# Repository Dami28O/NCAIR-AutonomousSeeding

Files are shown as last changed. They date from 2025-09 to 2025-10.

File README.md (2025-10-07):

# NCAIR Autonomous Seeding Robot - "Àgbẹ̀"

## Overview

This repository contains the documentation and codebase for **Àgbẹ̀**, an autonomous seeding robot developed during a Robotics Internship with the National Center for Artificial Intelligence and Robotics (NCAIR) in Abuja, Nigeria.

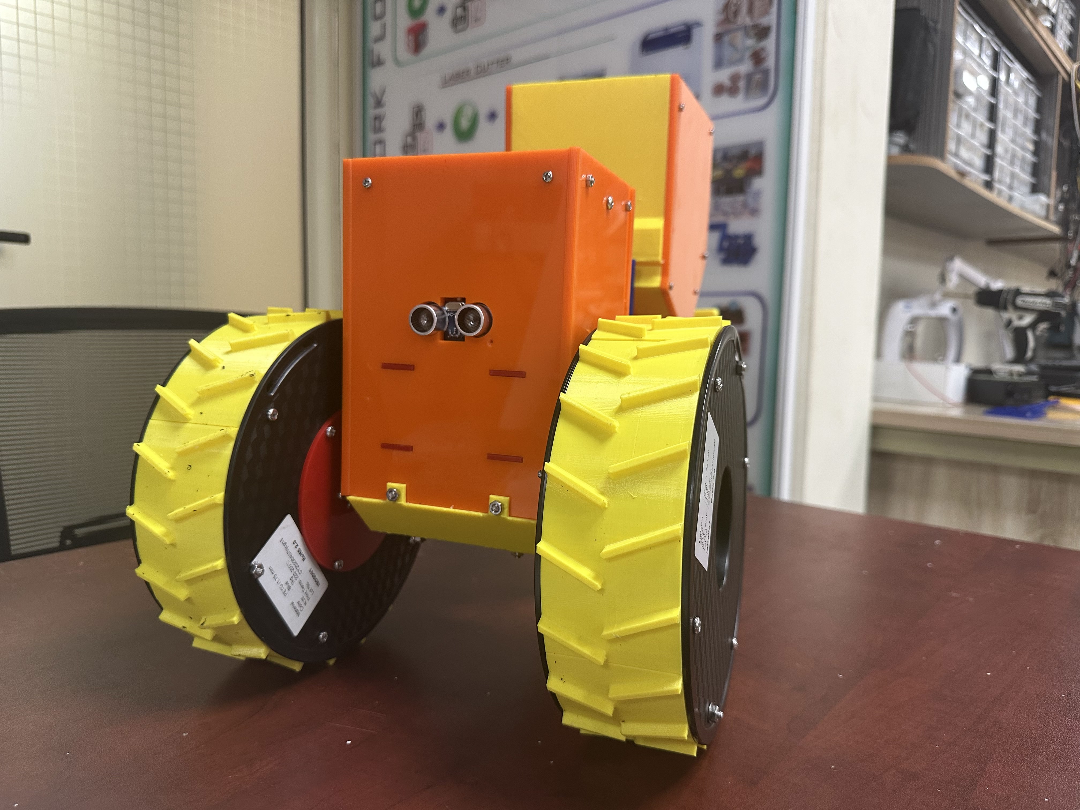
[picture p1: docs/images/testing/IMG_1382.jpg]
Àgbẹ̀


### Project Philosophy

- **Low Ground Pressure Design**: Minimizes soil compaction to preserve agricultural land quality
- **Swarm Approach**: Enables multiple units to work collaboratively for increased efficiency (Future Implementation)
- **Low Cost Solution**: Designed to be accessible and scalable for Nigerian agricultural contexts

---

# Repository Structure

```
NCAIR-AutonomousSeeding/
├── docs/
│   ├── hardware/
│   │   └── cad/                    # Fusion 360 CAD files
│   └── images/
│       ├── renders/                # 3D renders of the robot
│       ├── testing/                # Field testing images
│       ├── wiring/                 # Wiring diagrams
│       └── system_diagram/         # System architecture diagrams
├── architecture.md                 # Detailed description of the system architecture
├── evaluation.md                   # Evaluation of the current system
├── software/
│   ├── firmware/
│   │   ├── AutonomousSeeding.ino   # Motor control & sensor integration
│   │   └── wifi_comms.ino          # WiFi communication module
│   └── webapp/                     # Web application for robot control
│   │   ├── index.html  
│   │   ├── kalman.js
│   │   ├── main.js
│   │   └── styles.css 
├── architecture_evaluation.pdf     # Detailed architecture & product evaluation
├── assembly_guide.pdf              # Step-by-step assembly instructions
└── README.md                       # This file
```

---

## Architecture

For comprehensive details on the system architecture and product evaluation, please refer to [architecture.md](/docs/architecture.md) in the docs directory.

### System Overview

The Àgbẹ̀ robot employs a distributed control architecture with the following key components:

#### Hardware Architecture

**Mechanical Systems:**
- Low ground pressure chassis design (see `docs/hardware/cad/` for Fusion 360 files)
- Seeding mechanism with precise seed dispensing

**Electronics:**
- Microcontroller-based control system (Arduino-compatible)
- Sensor suite for navigation and environmental monitoring
- WiFi communication module for remote control
- Power management system

**Visual Resources:**
- **3D Models**: `docs/hardware/cad/` - Fusion 360 design files
- **Renders**: `docs/images/renders/` - High-quality visualizations
- **Wiring**: `docs/images/wiring/` - Complete wiring diagrams
- **System Diagrams**: `docs/images/system_diagram/` - Architecture overview

#### Software Architecture

**Firmware Layer:**

The robot operates on a dual-microcontroller architecture:

1. **Low-Level Control** (`software/firmware/AutonomousSeeding.ino`)
   - Motor control and PWM signal generation
   - Sensor data acquisition (GPS, IMU, proximity sensors)
   - Seeding mechanism actuation
   - Real-time control loops
   - Safety monitoring and emergency stop

2. **WiFi Communications** (`software/firmware/wifi_comms.ino`)
   - WiFi connectivity management
   - Remote command reception
   - Telemetry data transmission
   - Web interface integration

**Application Layer:**

3. **Web Application** (`software/webapp/`)
   - User interface for robot control
   - Real-time monitoring dashboard
   - Data visualization and logging
   - Framework: Vanilla JS

#### Communication Architecture

```
[Web Browser] <---> [Web App] <--WiFi--> [WiFi Comms Module] <--Serial--> [Low-Level Controller]

```
#### Technology Stack

**Embedded Systems:**
- Arduino-compatible microcontrollers
- C/C++ for firmware development
- Arduino Mega

**Web Technologies:**
- Frontend: Vanilla JS, Leaflet JS (GPS Visualisation) 
- WiFi communication protocol: HTTP

**Design Tools:**
- Autodesk Fusion 360 for mechanical design

---

## Documentation

### Core Documents

#### 📘 Architecture & Evaluation Documents
**File**: `architecture.md`

This comprehensive document covers:
- Detailed system architecture
- Hardware component specifications
- Software design rationale

**File**: `evaluation.md`
- Performance evaluation and testing results
- Design decisions and trade-offs

### Visual Documentation

#### `docs/images/renders/`
High-quality 3D renders showcasing:
- Complete robot assembly
- Individual subsystems

#### `docs/images/testing/`
Field testing documentation:
- Deployment photos
- Operational scenarios
- Performance demonstrations

#### `docs/images/wiring/`
Electrical documentation:
- Complete wiring diagrams
- Pin assignments
- Connection schematics
- Power distribution

#### `docs/images/system_diagram/`
System-level diagrams:
- Architecture overview
- Control system hierarchy
- Communication protocols

## Hardware Documentation

#### `docs/hardware/cad/`
Fusion 360 CAD files including:
- Complete assembly models
- Subsystem Model

---

## Getting Started

### Prerequisites

**Hardware Development:**
- Arduino IDE
- USB cable for microcontroller programming
- Components found in the [Bill Of Materials](/docs/BOM.md)

**CAD Viewing/Editing:**
- Autodesk Fusion 360 (for viewing/modifying CAD files)

**Web Development:**
- Webapp deployed locally from Python
- Web browser (Chrome/Firefox recommended)

### Assembly

1. **Mechanical Assembly**
   - Follow the complete instructions in `assembly_guide.pdf`
   - Use CAD files in `docs/hardware/cad/` for reference
   - Refer to `docs/images/renders/` for visual guidance

2. **Electronics Integration**
   - Follow wiring diagrams in `docs/images/wiring/`
   - Consult system diagrams in `docs/images/system_diagram/`
   - Double-check all connections before powering on

### Software Setup

#### Firmware Installation

**Low-Level Control Firmware**
```bash
    # Open AutonomousSeeding.ino in Arduino IDE
    # Select appropriate board and port
    # Open wifi_comms.ino in Arduino IDE
    # Configure WiFi credentials
    # Upload to primary microcontroller
```

#### Web Application Setup

```bash
cd software/webapp
python3 -m http.server 8080
```

---

## Usage

### Single Robot Operation

1. **Power On**: Flick Switch
2. **Connect**: Access web interface at [http://localhost:8080/] 
3. **Configure**: Set seeding parameters (spacing, depth, seed type)
4. **Deploy**: Define mission area and waypoints (Future implementation)
5. **Monitor**: Track progress via web dashboard

---

## Development

### Firmware Development

**Low-Level Control** (`software/firmware/AutonomousSeeding.ino`):
- Modify control algorithms
- Add new sensor support (Integration of rotary encoder)
- Adjust motor parameters
- Implement safety features

**WiFi Communications** (`software/firmware/wifi_comms.ino`):
- Update communication protocols
- Add new commands
- Improve telemetry
- Enhance swarm coordination

**Web Application** 
- Integration of kalman filter logic and tuning of kalman filter 
- Code structure optimisation

## Future Work

- [ ] Enhanced obstacle detection and avoidance
- [ ] Implement Boundary Detection and improved mapping
- [ ] Machine learning for optimal seeding patterns
- [ ] Extended battery life / solar integration
- [ ] Implement swarm algorithms for larger fleets
- [ ] Mobile app development
- [ ] Integration with precision agriculture sensors

---

## Acknowledgments

This project was completed as part of a Robotics Internship with the **National Center for Artificial Intelligence and Robotics (NCAIR)** in Abuja, Nigeria, under the National Information Technology Development Agency (NITDA).

### Project Name Origin

**Àgbẹ̀** - A Yoruba word meaning "farmer," reflecting the robot's purpose in supporting Nigerian agriculture.

## Quick Links

- 📘 [Architecture](/docs/architecture.md)
- 📘 [Evaluation](/docs/evaluation.md)
- 🔧 [Assembly Guide](/docs/assemblyGuide.md)
- 🎨 [3D Models (CAD)](./docs/hardware/cad/)
- 🖼️ [Renders](./docs/images/renders/)
- 📸 [Testing Photos](./docs/images/testing/)
- 🔌 [Wiring Diagrams](./docs/images/wiring/)
- 📊 [System Diagrams](./docs/images/system_diagram/)
- 💻 [Firmware](./software/firmware/)
- 🌐 [Web Application](./software/webapp/)

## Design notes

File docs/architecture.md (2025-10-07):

# System Architecture – Seeding Robot

## 1. Introduction
The seeding robot is designed to automate the process of planting seeds with consistent spacing and depth.  
This document explains the overall architecture, including the **mechanical design, electronics, software control**, and how these components interact.

---

## 2. System Overview
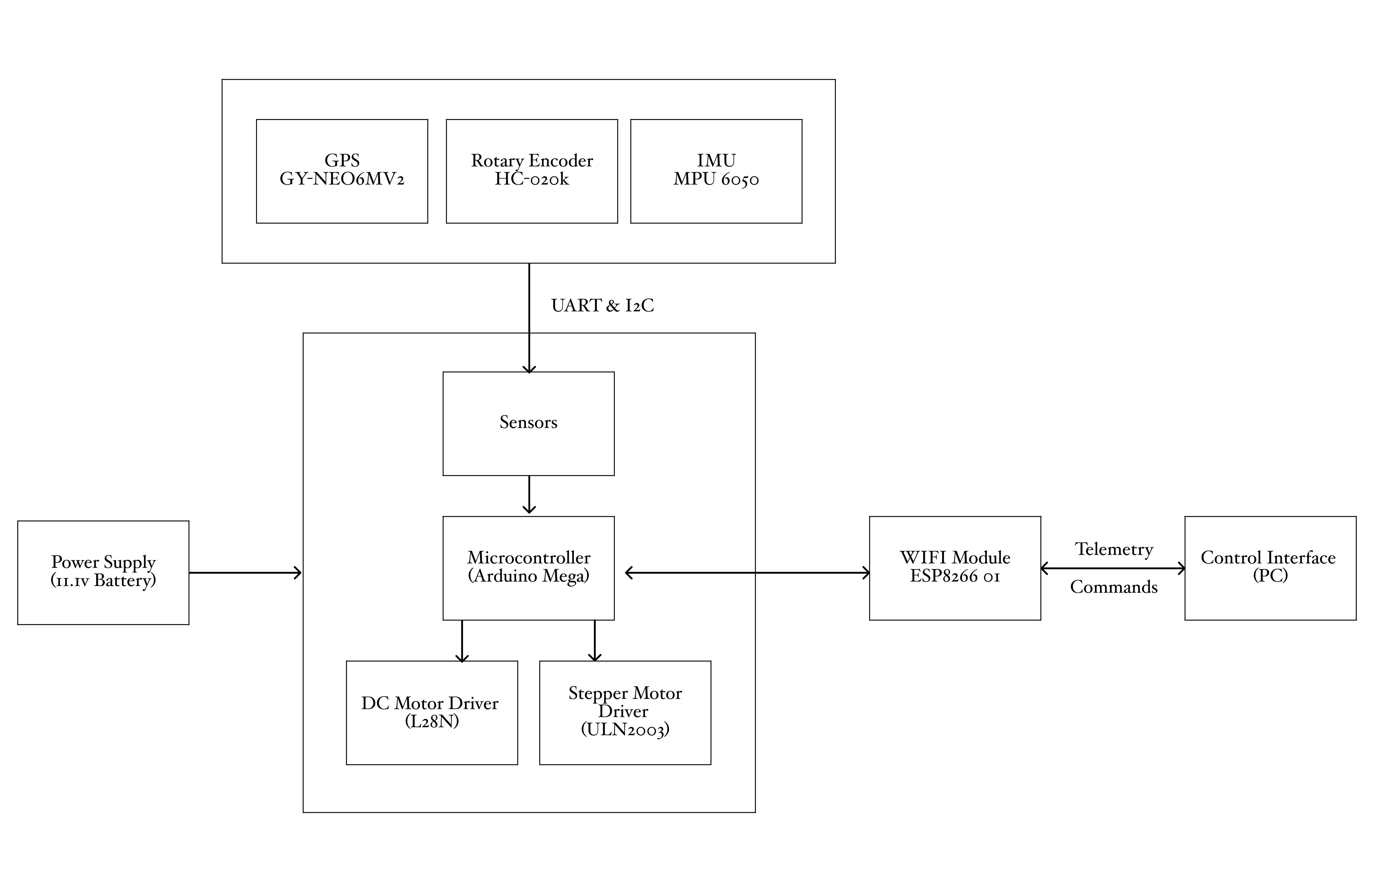
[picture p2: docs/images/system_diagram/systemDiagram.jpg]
System Block Diagram


The robot is divided into three main subsystems:
- **Mechanical** – chassis, wheel system, seed dispensing and furrow opening.
- **Electronics** – microcontroller, motor drivers, sensors, power supply, motors.
- **Software** – navigation and seed placement logic.

---

## 3. Mechanical Design
- **Chassis:** 
    - Dimensions: 632.74 x 278.00 × 390.47 mm (L × W × H).
    - Materials: Fabricated primarily from PLA (3D-printed components) and laser-cut acrylic sheets in 3 mm and 6 mm thicknesses, complemented by steel fasteners (M3, M4, M5 nuts, bolts, and washers) for structural integrity.
    - Wheels: The wheel assembly repurposes 198 mm-diameter recycled filament spools as the primary frame. Custom-designed PLA treads interlock with the spools and are mechanically fastened via screws to provide traction and durability.

- **Seeding Mechanism:**
    - **Seed Hopper & Feeding:** The hopper is designed with an angled base to direct seeds under gravity toward the dispensing mechanism. A 3D-printed converging funnel is installed at the outlet to constrain seed flow and minimize double-feeding. The geometry of the funnel is optimized to maintain a single-file feed, reducing seed bridging and clogging.

    - **Dispensing Mechanism:** At the base of the hopper, the dispensing unit is driven by a 28BYJ-48 Stepper Motor (precise 1.8° step angle). The motor is coupled to a laser-cut acrylic seed plate (interchangeable disc) with customizable pocket dimensions. Each pocket is sized according to seed diameter (e.g., 3–6 mm) and angular spacing, allowing adjustable seed drop frequency and spacing along the row. During rotation, each pocket aligns with an aperture slot at the bottom of the hopper, releasing a single seed through gravity drop.

    - **Furrow Opening & Closing:** The furrower is actuated via a rack-and-pinion mechanism coupled to a worm-and-spur gear train. A secondary stepper motor drives the worm, which in turn rotates the spur gear to raise or lower the rack. This motion adjusts the penetration depth of the furrow opener. The furrow opener itself consists of two 3 mm acrylic blades mounted on a pivot shaft with miniature ball bearings, allowing smooth rotation and reduced wear. The angled blades form a V-shaped cut, guiding soil outward to create a uniform seed trench.

- **Design considerations:**
    - **Soil resistance**: To overcome soil resistance during furrow actuation, a **worm gear** was selected to couple the stepper motor to the furrow mechanism due to its **non-backdrivability** and inherent torque multiplication. The chosen **28BYJ-48 stepper motors**, while offering low nominal torque, were favored for their **low power consumption** and compact form factor. To compensate for the torque limitations, a **1:60 gear reduction** was implemented between the worm gear and spur gear. This configuration substantially increased output torque, albeit at the expense of actuation speed. The reduced speed of raising and lowering the furrow was deemed acceptable given the critical requirement of ensuring sufficient penetration force in soil.

    - **Speed Spacing:** Seed spacing is governed by **wheel odometry**, derived from encoder counts at the rear wheel. For cost-efficiency, the system employs a **single rear-wheel encoder** rather than encoders on all wheels. With appropriate assumptions, this still yields an accurate estimate of distance traveled and thus seed placement intervals. Furthermore, the **planting interval is parameterizable via the web interface**, enabling calibration for different crop types and row spacing requirements.

    - **Wheel Configuration:** The robot employs a **tricycle-style wheel layout**, with a single drive wheel at the rear and two supporting wheels at the front. While unconventional, this arrangement was inspired by the **Fendt Xaver robot** design. A wider front wheelbase was chosen to enhance **lateral stability**, particularly in **tilled or soft soil conditions**, where narrower configurations risk instability or sinking.

    - **Electronics Housing:** 
        The electronics housing was designed to **integrate and protect** the power supply, microcontroller, and associated wiring within a single enclosure. This compartment is located at the **front of the robot**, serving a dual purpose:  
        1. **System Integration** – By consolidating the electronics into one housing, cable routing is minimized and maintenance is simplified, reducing potential points of failure in the field.  
        2. **Weight Distribution** – Positioning the housing at the front shifts the center of mass forward. When the seed hopper is fully loaded, this placement counterbalances the rear load and provides additional **downforce** on the furrow mechanism, improving soil penetration and stability during operation.

- CAD files are located in: [`/hardware/cad/`](../hardware/cad/).

---

## 4. Electronics
- **Microcontroller:** Arduino Mega
- **WIFI Module:** ESP8266 01
- **Motor Drivers:** 
    1. L28N Dual H-Bridge
    2. ULN2003 
- **Motors:**
    1. DC Motor with Gearhead 12VDC 74mA 1120 RPM ~ 1100 g-cm
    2. 28BYJ-48 stepper motors ~ 300g-cm
- **Sensors:** (GPS, IMU, encoders, soil sensors if any).  
    1. NEO6M-V2 GPS Module
    2. MPU6050 6DOF IMU
    3. HC-020K Rotary Encoder
    4. HC-SR04 Ultrasonic Sensor
- **Power Supply:** 11.1 Volt 3S Battery with 1200mAh

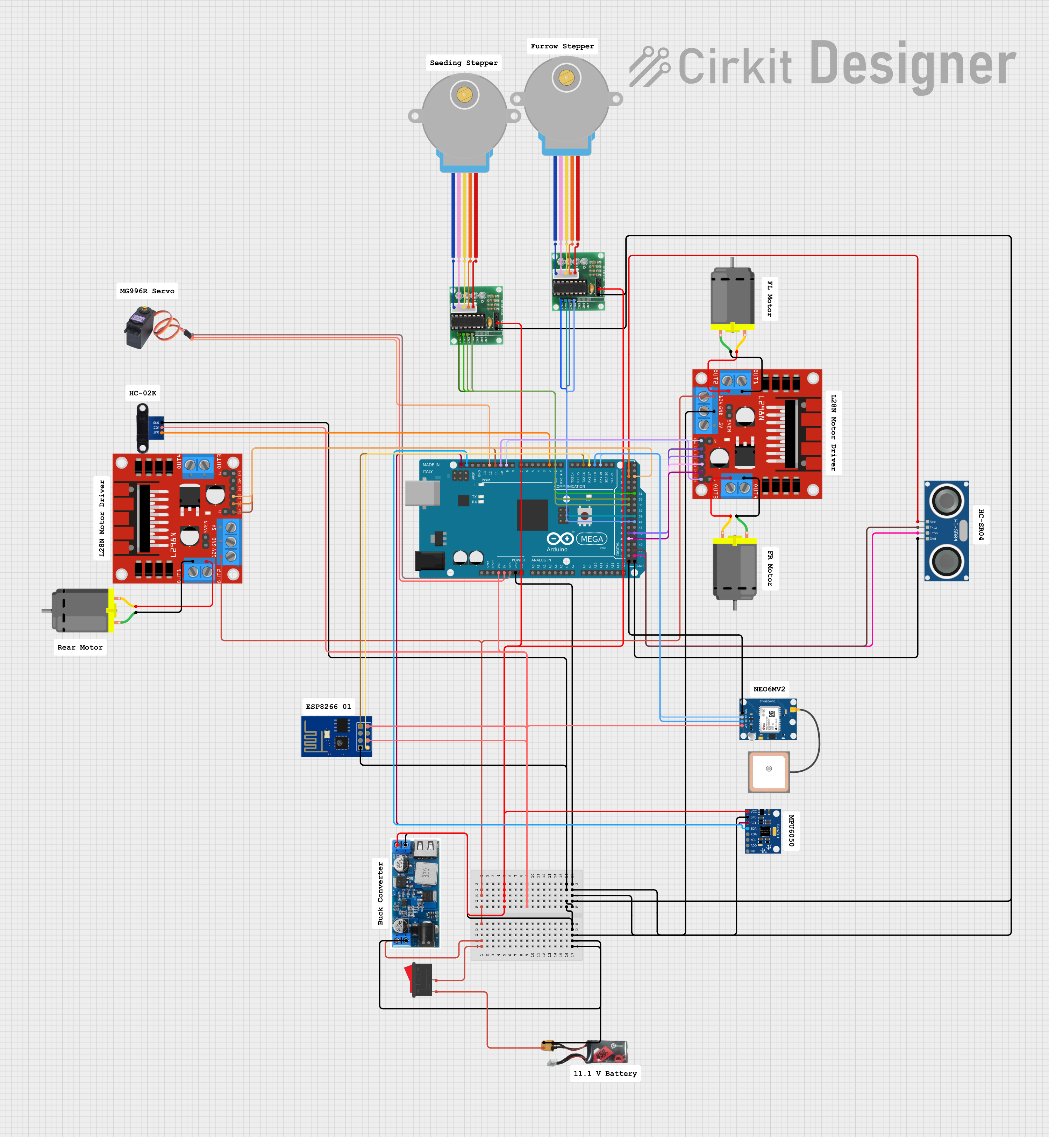
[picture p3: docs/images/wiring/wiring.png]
Wiring Diagram

Link: https://app.cirkitdesigner.com/project/0053ac62-e5af-4ed4-ab69-d646999af55c

---

## 5. Software Architecture
### 5.1 Control Layers
- **Low-Level (Firmware):** The low-level control is implemented on the Arduino Mega and is responsible for direct hardware interfacing and real-time task execution. This layer manages:
    - **Motor Control:**  
        - Implements PWM-based speed regulation for the DC drive motor via the L298N H-Bridge, supporting both forward and reverse motion.
        - Executes stepper motor sequencing for the 28BYJ-48 motors using the ULN2003 driver, enabling precise actuation of the seed dispensing plate and furrow depth mechanism.
        - Calculates differential wheel speeds based on Ackermann steering geometry, dynamically adjusting motor outputs for accurate path following.
    - **Sensor Polling & Data Acquisition:**  
        - Periodically reads encoder pulses from the HC-020K rotary encoder to compute wheel odometry and estimate linear displacement.
        - Polls the NEO6M-V2 GPS module and MPU6050 IMU over serial/I2C, parsing raw data for position and orientation updates.
        - Monitors the HC-SR04 ultrasonic sensor for obstacle detection, triggering avoidance routines if necessary.
    - **Seed Dispensing Logic:**  
        - Synchronizes seed drop timing with wheel odometry, activating the stepper-driven seed plate when the robot traverses the programmed interval distance.
        - Supports configurable seed spacing and drop frequency via parameters received from the web interface.
    - **Furrow Depth Actuation:**  
        - Controls the rack-and-pinion mechanism by driving the secondary stepper motor, adjusting furrow opener depth in response to user input or pre-set planting profiles.
    - **Communication:**  
        - Handles serial communication with the ESP8266 WiFi module, parsing incoming HTTP requests for control commands and transmitting sensor data to the web interface.
        - Implements a non-blocking main loop using timer interrupts and state machines to ensure responsive multitasking and minimize latency in sensor feedback and actuator control.
            - **Command Format:** HTTP GET requests to `http://<robot_ip>/<command>?speed=<val>&radius=<val>&depth=<val>`
            - **Supported Commands:** `forward`, `backward`, `left`, `right`, `stop`, `plant`, `pause_plant`, `furrow_up`, `furrow_down`
            - **Response Format:** JSON, e.g. `{"status":"OK"}`

- **High-Level:** navigation logic, sensor fusion (GPS + IMU + encoder).
    - **Navigation:**
        - In the current implementation, navigation and task execution are user-driven via the web-based control hub. The user interface allows manual specification of commands such as moving forward at a defined speed, planting seeds at a set depth, and executing turns with a configurable turning radius. These commands are transmitted to the robot as HTTP requests, which are parsed by the onboard ESP8266 module and relayed to the Arduino firmware for execution.
        - Each navigation command is mapped to low-level motor and actuator control routines, with parameters (speed, radius, depth) dynamically applied to the corresponding hardware interfaces. The robot does not autonomously plan its trajectory; instead, it responds to discrete user inputs in real time.
        - Future versions will incorporate autonomous navigation using path planning algorithms (e.g., A*, Dijkstra, or coverage planning) to optimise planting efficiency within a user-defined GPS boundary. The robot will continuously localize itself using fused GPS, IMU, and encoder data, and follow computed paths while automatically toggling planting actions based on its position and task schedule. This will enable fully autonomous operation, minimizing user intervention and maximizing throughput.
    - **Sensor Fusion:**  
        - Real-time localization of the robot is achieved through multi-sensor fusion using an extended Kalman filter (EKF), implemented off-board on the PC for computational efficiency and scalability. The decision to run the filter externally is driven by the high computational load and increased state dimensionality required for accurate pose estimation, which exceeds the capabilities of the onboard microcontroller.
        - The EKF prediction step integrates wheel odometry from the HC-020K rotary encoder and inertial measurements from the MPU6050 IMU (accelerometer and gyroscope). Since the IMU is limited to 6 degrees of freedom and lacks a magnetometer, absolute heading cannot be directly measured; instead, orientation is inferred by combining the servo steering angle and gyroscopic yaw rate, subject to kinematic constraints of the robot.
        - The correction step utilizes GPS position data from the NEO6M-V2 module, providing global 2D coordinates to correct drift in the predicted state. The filter fuses these asynchronous sensor streams, compensating for noise and bias, to output a continuous estimate of the robot’s position and orientation. This fused state is used for navigation, control, and logging, and can be extended to incorporate additional sensors or higher-order motion models as needed.

### 5.2 Autonomous Loop
```text
Start → Init (Read Sensors & Establish WiFi connection) → Get User Input → Start Operation 
→ [ Drive Forward → Lower Furrow → Plant Seeds → If Bounds < 2m → Pause Planting → Turn → Path Complete? ] 
→ If No → Repeat Loop 
→ If Yes → Stop

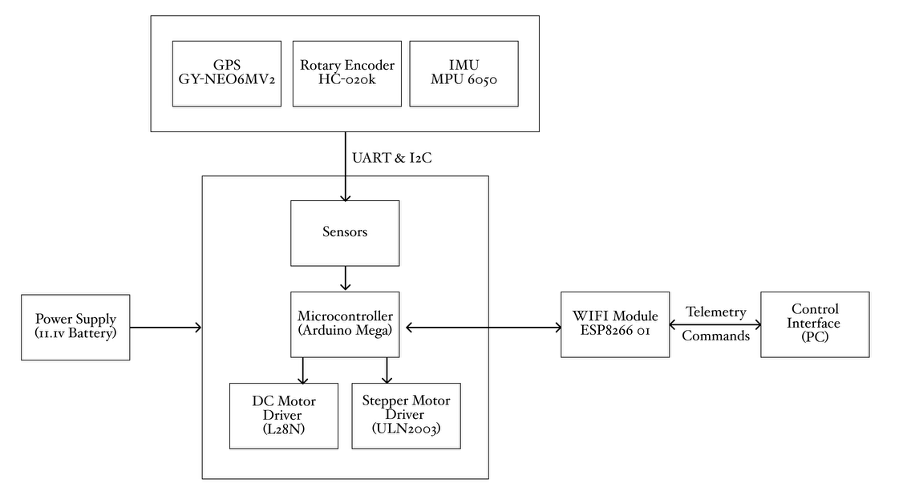
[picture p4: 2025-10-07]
docs/images/system_diagram/systemDiagram.png

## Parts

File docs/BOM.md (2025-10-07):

# Bill of Materials (BOM)

| Category | Component | Quantity | Purpose |
|---|---|---|---|
| **Motion** | Ultrasonic Sensor: HC-SR04 | 1 | Object detection to prevent collisions |
| | DC Motors | 3 | Motion |
| | Servo Motor (MG-996R) | 1 | 1× back wheel rotation |
| | Motor Driver: L298N | 2 | To drive the three wheels |
| | Rotary Encoder (Optical) - HC-020K | 1 | Backup for DC motor with encoder |
| | Neo 6m GPS | 1 | Robot localisation in space, used to create boundaries |
| | IMU - MPU6050 | 1 | To calculate orientation in space |
| **Seed Dispersion** | Stepper Motor: 28BYJ-48 (Box 068) | 2 | Turns the grate at set encoder readings to release grain at intervals |
| | Stepper Motor Driver: ULN2003 | 1 | Drives the stepper motor |
| | Ball Bearings | 2 | Furrow rotation |
| **MCU** | Arduino Mega | 1 | Main controller (“Brain”) |
| **Safety & Power** | Kill Switch | 1 | Stops the robot in case of malfunction |
| | Battery (11.1V) | 1 | Power supply |

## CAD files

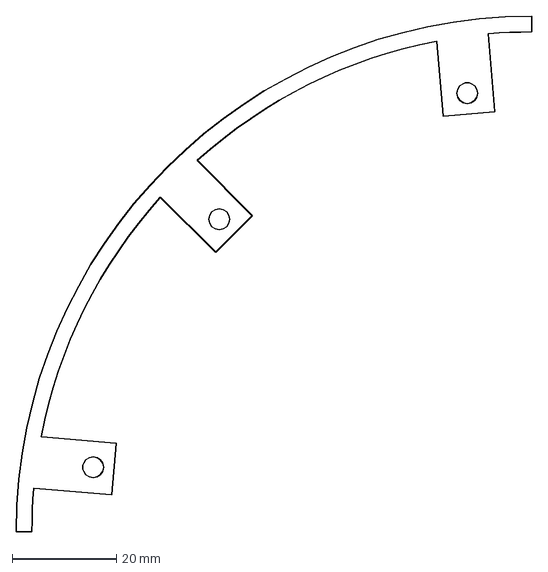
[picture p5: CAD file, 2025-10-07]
docs/hardware/cad/WheelGuide.dxf
99.0 x 99.0 mm

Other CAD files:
docs/hardware/cad/Seed Distribution System v19.f3z

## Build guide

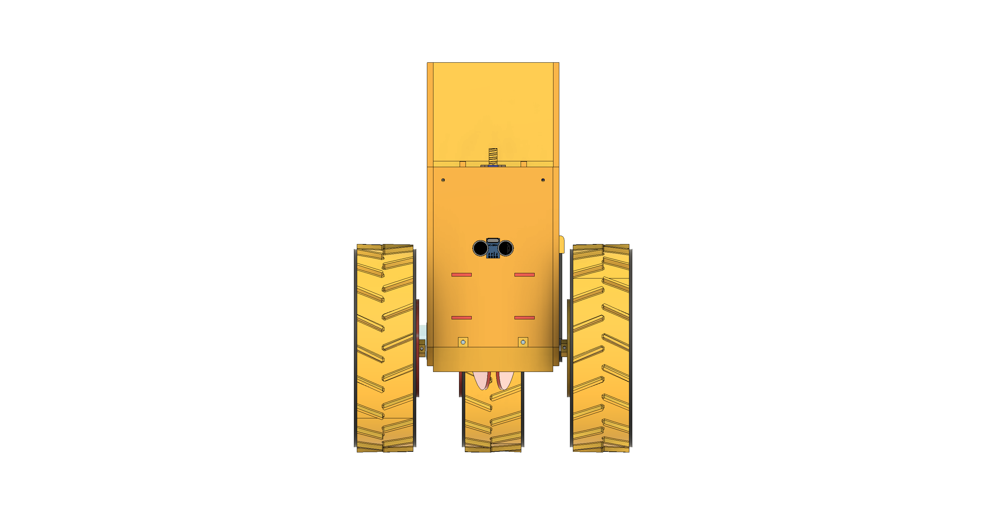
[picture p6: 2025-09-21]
docs/images/renders/Robot Assembly - FRONT.png

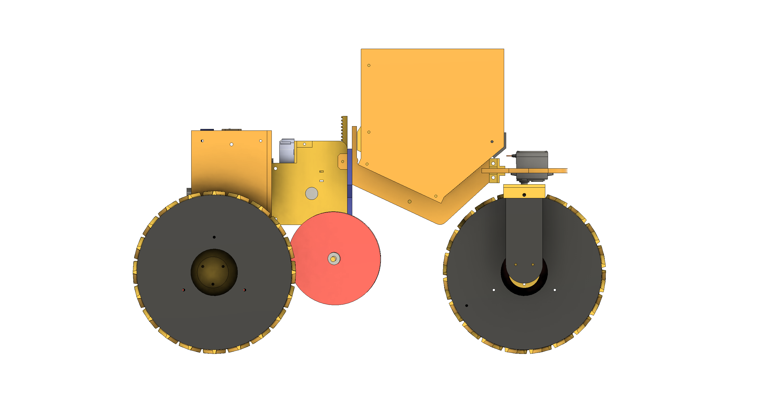
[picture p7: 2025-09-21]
docs/images/renders/Robot Assembly - LEFT.png

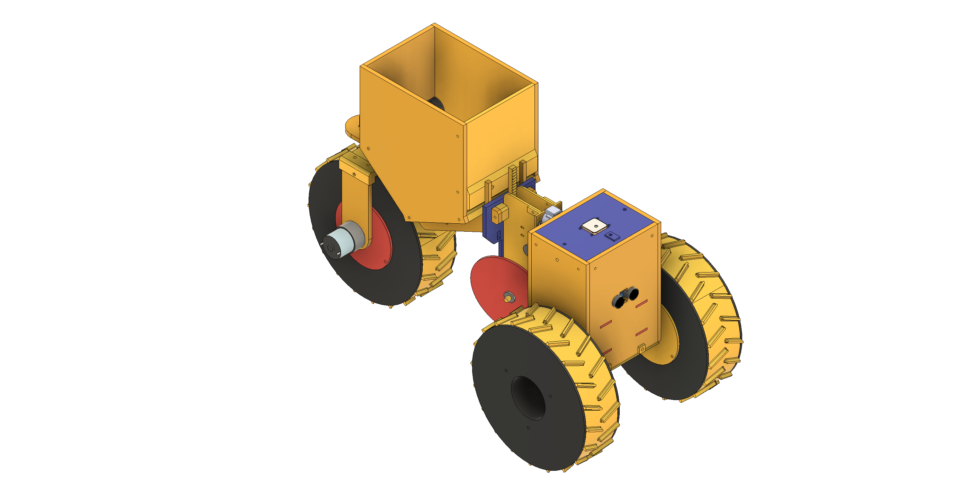
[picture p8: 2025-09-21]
docs/images/renders/Robot Assembly - ISO.png

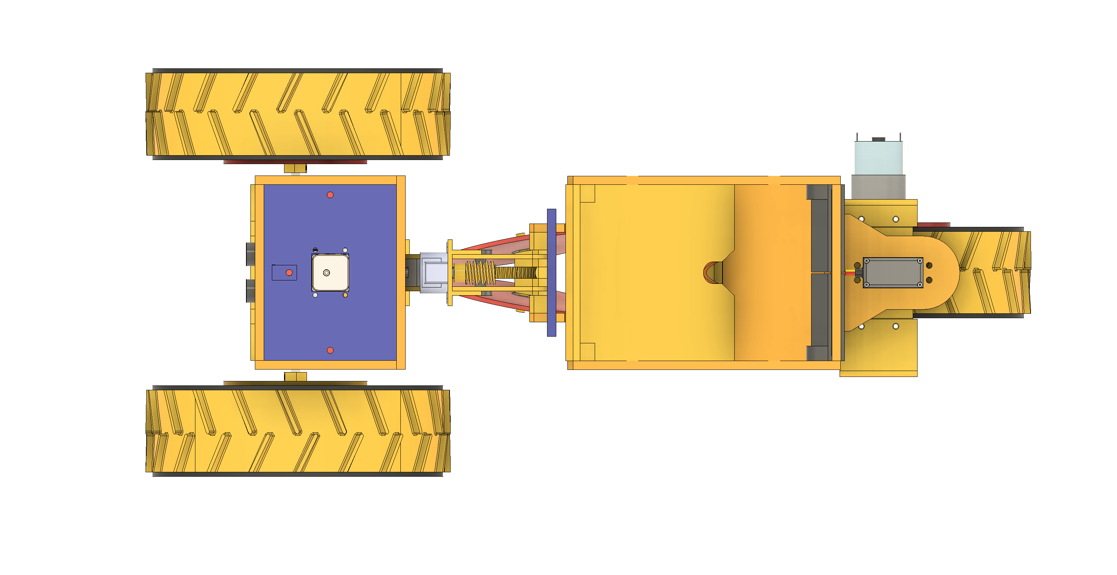
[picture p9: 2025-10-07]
docs/images/renders/Robot Assembly - TOP.png

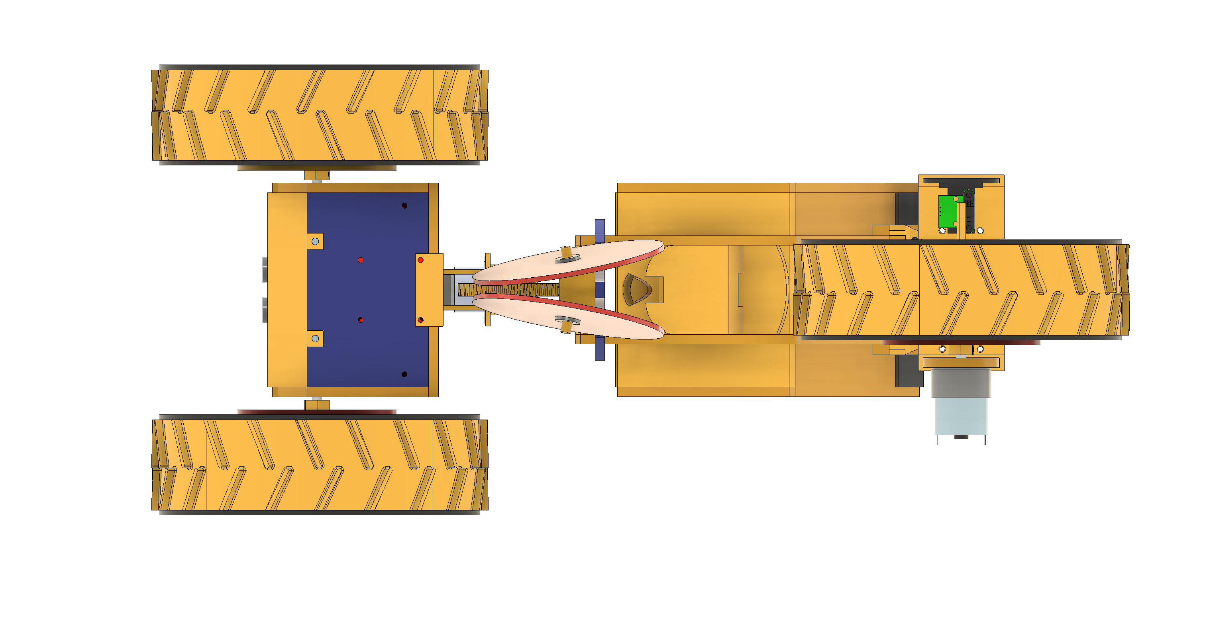
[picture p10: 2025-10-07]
docs/images/renders/Robot Assembly - BOTTOM.png

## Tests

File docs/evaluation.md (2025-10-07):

# Evaluation and Analysis of Current Implementation

## 1. Introduction

This document aims to critically analyse the current implementation and solution in addition to suggesting short-term and long-term improvements. Unfortunately a field test could not be completed, so it is likely further analysis needs to be conducted to understand how the robot performs in its operating environment. 

---

## 2. Mechanical Elements

### 2.1 Wheels

The current wheel design repurposes 3D printer filament spools as hubs, fitted with interlocking PLA treads. Due to the absence of a detailed assembly plan, inconsistencies arose during manufacturing—most notably, the rear wheel treads are slightly offset from center. This misalignment causes the raised tread sections to contact the servo mount, increasing friction, reducing drive efficiency, and occasionally stalling the motor. Such mechanical irregularities can introduce unpredictable behavior, complicating state estimation and localisation. To address this, future iterations should utilize the [Wheel Guide](/hardware/cad/WheelGuide.dxf) for precise assembly, and consider extending the guide to cover the full wheel circumference to prevent misalignment.

### 2.2 Structural Integrity 

The initial lack of a detailed assembly plan led to ad hoc design decisions regarding structural connections. While brass thermal inserts were considered for robust assembly, practical constraints necessitated alternative approaches, resulting in a structure with reduced rigidity. The modular design—comprising separate electronics housing, seed dispensing system, and rear wheel/servo modules—relies on a single laser-cut chassis piece for integration. Although this simplifies assembly, it introduces structural weak points and potential failure modes, particularly at the central chassis interface. For improved durability and reliability, future iterations should reinforce these connections and distribute mechanical loads across multiple attachment points to minimize dependence on a single structural element.

### 2.3 Design

Late-stage modifications to the electronics housing, such as adding an access port for Arduino debugging and firmware updates, were not fully integrated into the initial design. As a result, the port’s placement requires removal of the front right wheel for access, increasing maintenance complexity and accelerating wear on the wheel hub assembly. Similarly, the allocated space for battery recharging proved inadequate once the robot was fully assembled, complicating routine servicing. These oversights highlight the importance of design-for-maintenance principles; future iterations should prioritize accessible component placement and serviceability to streamline development, testing, and field repairs.

Assembly complexity was a significant challenge, particularly within the electronics hub. Once the battery and power distribution circuitry were installed, wiring became congested and disorganized, complicating both assembly and subsequent debugging. This increased build time and hindered fault isolation during testing. To address these issues, future iterations should implement systematic cable management and consider integrating a custom PCB to minimize external wiring and streamline assembly.

---

## 3. Software Elements 

### 3.1 Encoder

At this stage, the rotary encoder was not installed due to sourcing delays, limiting state estimation to low-frequency GPS updates. This constraint prevents accurate real-time odometry and degrades localisation performance, especially during maneuvers. Even with a rear-mounted encoder, wheel slippage can introduce measurement errors, and the absence of front wheel encoders impedes precise tracking during turns. While heading estimation can be partially compensated using gyroscope data, closed-loop speed and position control of the drive motors remains challenging without direct feedback. For the current semi-autonomous setup, users must manually estimate turn completion, which is inefficient and unreliable. Future designs should incorporate encoders on all driven wheels and consider mechanical improvements to minimise slippage, ensuring robust odometry for autonomous operation.

### 3.2 Sensor Fusion

While sensor fusion has been implemented on the PC side in javascript, further work needs be done to poll the sensors correctly from the robot. Currently, only GPS data is being transmitted so the remaining sensors have not been configured to send data properly, however timings can be inferred from the [mention file]

---

## 4. Further Implementation

### 4.1 Suspension

The current robot design lacks any form of suspension system, which significantly impacts its stability and operational reliability when traversing uneven or soft agricultural terrain. In the absence of suspension, shocks and vibrations from obstacles such as potholes, clods, or ruts are directly transmitted to the chassis and sensitive components, increasing the risk of mechanical wear, sensor inaccuracies, and loss of traction. This issue is exacerbated under load, where weight distribution can further amplify instability and wheel slip, potentially leading to erratic motion or stalling.

Integrating a suspension mechanism—such as spring-damper assemblies or flexible linkages—would decouple the chassis from ground-induced disturbances, maintaining consistent wheel contact and improving both traction and ride quality. This enhancement would not only protect onboard electronics and actuators from mechanical stress but also contribute to more accurate odometry and sensor readings, which are critical for reliable navigation and seed placement. Future iterations should prioritize the evaluation and implementation of suitable suspension architectures tailored for low-speed, lightweight field robots.

### 4.2 Navigation

As highlighted the current implementation is semi-autonomous but requires a lot of human input and monitoring for it be used. Implementing a navigation algorithm for path planning would enable this system to become fully autonomous. Below are some papers that tackle the issue of path planning for this exact use case.

**Relevant Links:**
- https://arxiv.org/abs/2210.07838
- https://www.mdpi.com/2073-4395/10/10/1608#:~:text=Agricultural%20field%20operations%20such%20as,ends%20at%20the%20same%20depot.

### 4.3 Modular Attachments

While this MVP is focused on seeding, the robot’s architecture is inherently modular, enabling rapid adaptation for a variety of agricultural tasks through interchangeable attachments. Adopting a tool-change paradigm similar to [OZ](https://www.naio-technologies.com/en/oz-robot/) by Naio Technologies, future iterations could support quick-swap modules for expanded functionality.

Potential modules include:
- **Camera Module:** Enables crop monitoring, weed and pest detection, and plant health assessment. Integrating an onboard computer vision pipeline would allow real-time analysis and decision-making in the field.
- **Weeding Module:** Mechanically removes weeds identified by the vision system, supporting precision agriculture and reducing manual labor. This could leverage existing mechanical or chemical weeding solutions, triggered by the detection module.

The modular approach not only increases the robot’s versatility but also streamlines maintenance and upgrades, as individual components can be serviced or replaced independently. Future work should focus on standardizing mechanical and electrical interfaces for attachments, and developing a robust software framework for dynamic tool recognition and control.

**Relevant Links:**
- https://link.springer.com/article/10.1007/s43154-022-00086-5

### 4.4 Swarm Approach

To further enhance operational efficiency, a swarm paradigm could be implemented, enabling multiple robots to collaboratively cover larger field areas. This approach allows the system to achieve throughput comparable to that of larger agricultural machinery, while minimising soil compaction and damage due to the distributed weight of smaller units. Swarm robotics also facilitates task specialisation, where individual robots can be equipped with different attachments (e.g., seeding, weeding, monitoring) and coordinate their actions to address diverse farm requirements. Implementing robust inter-robot communication and decentralized task allocation algorithms will be essential for effective collaboration and scalability in real-world agricultural environments.

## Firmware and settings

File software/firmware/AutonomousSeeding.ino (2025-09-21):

#include <Servo.h>
#include <AccelStepper.h>
#include <math.h>
#include <TinyGPSPlus.h>

// ---------------------------------------------------
//              PIN DEFINITIONS                       
// ---------------------------------------------------

// ------------ ULTRASONIC SENSOR
#define trigPin 52
#define echoPin 53

// ------------ DC MOTORS
// FR Motor connections
const uint8_t enFR = 9;
const uint8_t in1 = 44;
const uint8_t in2 = 45;

// FL Motor connections
const uint8_t enFL = 10;
const uint8_t in3 = 46;
const uint8_t in4 = 47;

// REAR Motor Connections
const uint8_t enREAR = 11;
const uint8_t REAR_in1 = 24;
const uint8_t REAR_in2 = 25;

// ------------ REAR SERVO
const uint8_t ServoSignal = 12;

// ------------ STEPPER MOTORS
#define HALFSTEP 8
AccelStepper seedingStepper(HALFSTEP, 30, 32, 31, 34); 
AccelStepper furrowStepper(HALFSTEP, 38, 40, 39, 41);


// ---------------------------------------------------
//              VARIABLE DEFINITIONS                       
// ---------------------------------------------------
const float WHEELBASE = 39.6;   // Distance between front and rear axles in cm
const float TRACK_WIDTH = 21.6; // Distance between front and rear axles in cm
int currentSpeed = 0;
bool isMovingForward = false;         
bool isDown = false;                            // Flag for furrow up or down
float furrowDepth = 0.0;                        // Gives us the depth of the furrow
const int MAX_DEPTH = 5;                        // Max depth of the furrow
const int STEPS_PER_REV = 2048;                 // for 28BYJ-48 in half-step mode
const int STEPS_30_DEG = STEPS_PER_REV / 12;    // ~170 steps for 30 degrees
const int DEFAULT_FURROW_ROT = 5;               // Default number of rotations to lower furrow to 3cm below ground 
bool planting = false;                          // Flag for planting mode or not 
unsigned long lastSeedDrop = 0;                 // Timer between seed drops
String lastMotionCommand = "";                  // Store the last valid motion command
bool stoppedByObstacle = false;                 // Flag to track if the stop was due to an obstacle
float lat = 9.0563;                             // last GPS lat and lon
float lng = 7.4985;
unsigned long lastGPSUpdate = 0;                // Timer for GPS updates
unsigned long servoMoveStartTime = 0;           // Timer to track servo movement  
bool servoMoving = false;                       // Flag to indicate if servo is moving 


// ---------------------------------------------------
//                   INSTANCES                      
// ---------------------------------------------------

Servo rearServo;                  // SERVO OBJECT
TinyGPSPlus gps;                  // GPS OBJECT


// ---------------------------------------------------
//              FUNCTION PROTOTYPES                      
// ---------------------------------------------------
void raiseFurrow(int numRot = DEFAULT_FURROW_ROT);
void lowerFurrow(int numRot = DEFAULT_FURROW_ROT);
void setupMotors();
void setupDCMotors();
void setupStepperServo();
void setupSensors();
void processCommand(String command);
int radiusToServoAngle(float radius, char dir);
void turn(char dir, int angle, float radius);
void rotateWheel(int angle);
void driveForward(float speed);
void driveBackward(float speed);
void stopMotors();
long readUltrasonic();
bool isServoReady();


// ---------------------------------------------------
//                   SETUP                      
// ---------------------------------------------------
void setup() {
  Serial.begin(9600);
  Serial1.begin(9600);                // GPS Serial

  // initialise the wifi connection
  initWiFi();

  // Setup robot functions
  setupMotors();
  setupStepperServo();
  setupSensors();

  // ------ SERVO ------ //
  rearServo.attach(ServoSignal);        // Servo signal wire → pin 12
  rearServo.write(90);        // Start centered
}

// -------------- SETUP FUNCTIONS -------------- //


void setupMotors() {
  setupDCMotors();
  setupStepperServo();
}

void setupDCMotors() {
  // Set all the motor control pins to outputs
  pinMode(enFR, OUTPUT);
  pinMode(enFL, OUTPUT);
  pinMode(enREAR, OUTPUT);
  pinMode(in1, OUTPUT);
  pinMode(in2, OUTPUT);
  pinMode(in3, OUTPUT);
  pinMode(in4, OUTPUT);
  pinMode(REAR_in1, OUTPUT);
  pinMode(REAR_in2, OUTPUT);

  // Turn off motors - Initial state
  digitalWrite(in1, LOW);
  digitalWrite(in2, LOW);
  digitalWrite(in3, LOW);
  digitalWrite(in4, LOW);
  digitalWrite(REAR_in1, LOW);
  digitalWrite(REAR_in2, LOW);
}

void setupStepperServo() {
  // Function to set up direction servo and two stepper motors

  // SERVO
  rearServo.attach(ServoSignal);        // Servo signal wire → pin 12
  rearServo.write(90);                  // Start centered

  // STEPPERS
  // Setup speed and acceleration for furrow and seeding stepper motors
  furrowStepper.setMaxSpeed(1000.0);
  furrowStepper.setAcceleration(50.0);

  seedingStepper.setMaxSpeed(1000.0);
  seedingStepper.setAcceleration(50.0);

  // Upon initialisation load the seeds to be ready for dropping
  loadSeeds();
}

void setupSensors() {
  // Set up ultrasonic sensor
  pinMode(trigPin, OUTPUT);
  pinMode(echoPin, INPUT);
}

// ---------- COMMAND PROCESSOR ----------- //
void processCommand(String command) {
  command.trim();                 // clean whitespace
  command.toUpperCase();          // Case insensitive

  if (command.startsWith("F")) {
    lastMotionCommand = command;                                // Save the direction and speed
    int speed = command.substring(1).toFloat();
    rotateWheel(90);
    driveForward(speed);
  } 
  else if (command.startsWith("B")) {
    lastMotionCommand = command;                                // Save the direction and speed
    int speed = command.substring(1).toFloat();
    rotateWheel(90);
    driveBackward(speed);
  }
  else if (command.startsWith("S")) {
    lastMotionCommand = "";                                     // Clear motion profile
    stopMotors();
  }
  else if (command.startsWith("L") || command.startsWith("R")) {
    lastMotionCommand = command;                                    // Save information on turning in case of obstacle
    char direction = command[0];                                    // Get direction from command
    float turningRadius = command.substring(1).toFloat();           // [cm]
    int angle = radiusToServoAngle(turningRadius, direction);       // Convert turning radius to angle 
    stopMotors();                                                   // Pause Motion
    
    turn(direction, angle, turningRadius);                           // Apply Ackermann Steering
  }
  else if (command.startsWith("U")) {
    // If the furrow is already down then bring back up
    if (isDown) {
      raiseFurrow();
    }
    else {
      Serial.println("Furrow is already up");
    }
  }
  else if (command.startsWith("D")) {
    if (isDown) {
      Serial.println("Furrow is already down");
    }
    else {
      lowerFurrow();
    }
  }
  else if (command == "PLANT") {
    // GO for planting seeds
    planting = true;
    Serial.println("Seeding mode activated");
  }
  else if (command == "PAUSE") {
    // GO for planting seeds
    planting = false;
    Serial.println("Seeding mode deactivated");
  }
  else {
    Serial.println("Invalid command.");
  }
}

// -------------- LOCOMOTION -------------- //
int radiusToServoAngle(float radius, char dir) {
  // Handle special cases
  if (radius <= 0) {
    Serial.println("Error: Radius must be positive");
    return 90;                                            // Return center position for invalid input
  }
  
  if (radius > 1000) {                                    // Very large radius = straight line
    return 90;
  }

  Serial.print("Direction "); Serial.println(dir);

  // Calculate steering angle with Ackermann steering
  float steeringAngleRad = atan(WHEELBASE / radius);
  float steeringAngleDeg = steeringAngleRad * 180.0 / PI; // Convert to degrees

  // Convert to servo position
  int servoAngle = (dir == 'R') ? (90 - (int)steeringAngleDeg) : (90 + (int)steeringAngleDeg);

  
  // Constrain to servo limits
  servoAngle = constrain(servoAngle, 0, 180);

  // Debug output
  Serial.print("Radius: "); Serial.print(radius);
  Serial.print(" cm -> Steering angle: "); Serial.print(steeringAngleDeg);
  Serial.print("° -> Servo angle: "); Serial.println(servoAngle);
  
  return servoAngle;
}


void turn(char dir, int angle, float radius) {
  int vR = 100;                          // Speed of rear wheel (PWM)
  int vFR = 0;                           // Initialise speed of front right wheel
  int vFL = 0;                           // Initialise speed of front right wheel
  // Turn the back wheel 
  rotateWheel(angle);
  
  while (!isServoReady()) {
    delay(10);  // Small delay to prevent busy waiting
  }


  // Compute Ackerman steering velocities
  if (dir == 'R') {
    vFR = round(vR * ((radius - TRACK_WIDTH / 2) / radius));
    vFL = round(vR * ((radius + TRACK_WIDTH / 2) / radius));
  }
  else {
    vFR = round(vR * ((radius + TRACK_WIDTH / 2) / radius));
    vFL = round(vR * ((radius - TRACK_WIDTH / 2) / radius));
  }

  // Constrain to valid PWM values
  vFR = constrain(vFR, 0, 255);
  vFL = constrain(vFL, 0, 255);

  // Apply calculated speed to drive motors
  // Set speed
  analogWrite(enFR, vFR);
  analogWrite(enFL, vFL);
  analogWrite(enREAR, vR);

  // Drive all three motors
  digitalWrite(in1, HIGH); digitalWrite(in2, LOW);
  digitalWrite(in3, LOW); digitalWrite(in4, HIGH); 
  digitalWrite(REAR_in1, LOW); digitalWrite(REAR_in2, HIGH);
  
  // Update state variables
  isMovingForward = true;
  currentSpeed = vR;

  Serial.print("Turning at "); Serial.println(vR);


  Serial.print("Rear servo angle: "); Serial.print(angle); Serial.print(" | ");
  Serial.print("Right Wheel Speed: "); Serial.print(vFR); Serial.print(" | ");
  Serial.print("Left Wheel Speed: "); Serial.println(vFL);
}

void rotateWheel (int angle) {
  rearServo.write(angle);
  servoMoveStartTime = millis();
  servoMoving = true;
  Serial.print("Moved to: ");
  Serial.println(angle);
}

bool isServoReady() {
  if (!servoMoving) return true;
  
  if (millis() - servoMoveStartTime > 600) {  // Adjust timing
    servoMoving = false;
    return true;
  }
  return false;
}

void driveForward(float speed) {
  // convert speed percent to PWM signal
  int PWM = int((speed/100) * 255);

  // Set speed
  analogWrite(enFR, PWM);
  analogWrite(enFL, PWM);
  analogWrite(enREAR, PWM);

  // Drive all three motors
  digitalWrite(in1, HIGH); digitalWrite(in2, LOW);
  digitalWrite(in3, LOW); digitalWrite(in4, HIGH); 
  digitalWrite(REAR_in1, LOW); digitalWrite(REAR_in2, HIGH);
  
  // Update state variables
  isMovingForward = true;
  currentSpeed = PWM;

  Serial.print("Driving forward at: "); Serial.println(PWM);
}

void driveBackward(float speed) {
  // convert speed percent to PWM signal
  int PWM = int((speed/100) * 255);

  // Set speed
  analogWrite(enFR, PWM);
  analogWrite(enFL, PWM);
  analogWrite(enREAR, PWM);

  // Drive all three motors
  digitalWrite(in1, LOW); digitalWrite(in2, HIGH);
  digitalWrite(in3, HIGH); digitalWrite(in4, LOW);
  digitalWrite(REAR_in1, HIGH); digitalWrite(REAR_in2, LOW);

  // Update state variables
  isMovingForward = false;
  currentSpeed = PWM;

  Serial.print("Driving backward at: "); Serial.println(PWM);
}

void stopMotors(){

  // Set PWM to 0
  analogWrite(enFR, 0);
  analogWrite(enFL, 0);
  analogWrite(enREAR, 0);

  // Update State Variables
  isMovingForward = false;
  currentSpeed = 0;
  

  Serial.print("Stopping DC Motor"); Serial.print(" | "); Serial.println("Planting Paused");
}

void resumeMotion() {
  // Check if there's a stored command to resume
  if (lastMotionCommand.length() > 0) {
    if (lastMotionCommand.startsWith("F")) {
      int speed = lastMotionCommand.substring(1).toFloat();
      driveForward(speed);
    } else if (lastMotionCommand.startsWith("B")) {
      int speed = lastMotionCommand.substring(1).toFloat();
      driveBackward(speed);
    } else if (lastMotionCommand.startsWith("L") || lastMotionCommand.startsWith("R")) {
      char direction = lastMotionCommand[0];                                    // Get direction from command
      float turningRadius = lastMotionCommand.substring(1).toFloat();           // [cm]
      int angle = radiusToServoAngle(turningRadius, direction);       // Convert turning radius to angle 
      stopMotors();                                                   // Pause Motion
      
      turn(direction, angle, turningRadius);                           // Apply Ackermann Steering
    }
  }
}

// ----------- FURROW ------------ //
void raiseFurrow(int numRot = DEFAULT_FURROW_ROT) {
  furrowStepper.moveTo(STEPS_PER_REV * numRot);              // Stepper moves anticlockwise
  furrowStepper.run();
  isDown = false;
  Serial.println("Furrow position reset");
}

void lowerFurrow(int numRot = DEFAULT_FURROW_ROT) {
  furrowStepper.moveTo(STEPS_PER_REV * -numRot);              // Stepper moves clockwise
  furrowStepper.run();
  isDown = true; 
  Serial.println("Furrow is now lowered");
}

// ----------- SEEDING ------------ //

void loadSeeds() {
  // Function to spin the stepper motor for the seeds so that it is ready to drop seeds periodically
  seedingStepper.moveTo(STEPS_30_DEG * 5);
  seedingStepper.run();
  lastSeedDrop = millis();
  Serial.println("Seeds ready to drop");
}

void dropSeeds() {
  // Rotate 30 degrees to drop one seed at a time
  seedingStepper.moveTo(seedingStepper.currentPosition() + STEPS_30_DEG);
  Serial.println("Seed dropped");
}

// ----------- SENSORS ------------ //

long readUltrasonic() {
  digitalWrite(trigPin, LOW);
  delayMicroseconds(2);
  digitalWrite(trigPin, HIGH);
  delayMicroseconds(10);
  digitalWrite(trigPin, LOW);
  long duration = pulseIn(echoPin, HIGH);
  return duration * 0.034 / 2; // cm
}

// GPS 
void simulateGPSMovement() {
  if (millis() - lastGPSUpdate > 5000) { // Update every 5 seconds
    // Simulate small random movements
    lat += (random(-10, 11) / 100000.0);
    lng += (random(-10, 11) / 100000.0);
    lastGPSUpdate = millis();
    
    Serial.print("GPS Update: ");
    Serial.print(lat, 6);
    Serial.print(", ");
    Serial.println(lng, 6);
  }
}



void loop() {
  // CHECK OBSTACLES AHEAD
  float distance = readUltrasonic();
  // Serial.print("Distance: ");
  // Serial.println(distance);

  // if valid gps data, pass that to the web-app else simulate ut
  if (Serial1.available()) {
    if (gps.encode(Serial1.read()) && gps.location.isValid()) { // if we can read the serial data and it is valid
      if (millis() - lastGPSUpdate > 5000) {
        lat = gps.location.lat();
        lng = gps.location.lng();
        lastGPSUpdate = millis();
      }
    }
  }
  else {
    simulateGPSMovement();
  }
  

  if (distance < 20 && isMovingForward) {
    stoppedByObstacle = true;
    stopMotors();
    Serial.println("Obstacle detected! Motors stopped.");
  }
  else if (stoppedByObstacle && distance >= 20) {
    // Resume prior action 
    resumeMotion();
    stoppedByObstacle = false;                    // Reset the flag after resuming
  }

  if (planting && isMovingForward) {
    // if in planting mode and the time since last drop is more than 2s -> drop a seed
    if (millis() - lastSeedDrop >= 2000) {
      dropSeeds();
      lastSeedDrop = millis();
    }
  }

  handleWiFiCommands();
  
  // Check for serial input
  if (Serial.available()) {
    String input = Serial.readStringUntil('\n');
    processCommand(input);
  }

  delay(10);
}

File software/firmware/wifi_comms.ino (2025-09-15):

// Handles all wifi communications for robot control
#include <WiFiEspAT.h>


// WiFi credentials for Access Point
char ssid[] = "AGBE";     
char pass[] = "AGBE@Seeding"; 

WiFiServer server(80); // Standard HTTP port

// ---------- FUNCTION DECLARATIONS
void sendWiFiResponse(WiFiClient client, String message, String contentType = "text/html");
String processWiFiCommand(String request);
int extractSpeedParameter(String request, int defaultSpeed);
float extractRadiusParameter(String request, float defaultRadius);
float extractDepthParameter(String request, float defaultDepth);

// Initialize WiFi
void initWiFi() {
  Serial2.begin(115200);   // ESP8266 connection

  Serial.println("=== Arduino Robot Control ===");
  Serial.println("Starting WiFi setup...");

  WiFi.init(&Serial2);

  // Check ESP8266 connection
  if (WiFi.status() == WL_NO_MODULE) {
    Serial.println("ERROR: ESP8266 not found!");
    Serial.println("Check wiring:");
    Serial.println("  ESP8266 TX -> Arduino Pin 17 (RX2)");
    Serial.println("  ESP8266 RX -> Arduino Pin 16 (TX2)");
    Serial.println("  ESP8266 VCC -> 3.3V");
    Serial.println("  ESP8266 GND -> GND");
    while (true) {
      delay(1000);
    }
  }

  Serial.println("ESP8266 found!");
  Serial.print("Creating Access Point: ");
  Serial.println(ssid);

  // Start Access Point
  if (WiFi.beginAP(ssid, pass) != WL_AP_LISTENING) {
    Serial.println("Failed to create Access Point!");
    while (true) {
      delay(1000);
    }
  }

  delay(3000);  // Give it time to stabilize

  Serial.println("SUCCESS: Access Point created!");
  Serial.print("Network Name: ");
  Serial.println(ssid);
  Serial.print("Password: ");
  Serial.println(pass);
  Serial.println("Then go to: http://192.168.4.1");
  Serial.println("");
  Serial.println("=== Ready for commands ===");

  server.begin();

}
// Extract speed parameter from URL
int extractSpeedParameter(String request, int defaultSpeed) {
  int speedIndex = request.indexOf("speed=");
  if (speedIndex != -1) {
    int startPos = speedIndex + 6; // Length of "speed="
    int endPos = request.indexOf('&', startPos);
    if (endPos == -1) endPos = request.indexOf(' ', startPos);
    if (endPos == -1) endPos = request.length();
    
    String speedStr = request.substring(startPos, endPos);
    int speed = speedStr.toInt();
    
    // Constrain speed to reasonable limits
    if (speed > 0 && speed <= 100) {
      return speed;
    }
  }
  return defaultSpeed;
}

// Extract turning radius parameter from URL
float extractRadiusParameter(String request, float defaultRadius) {
  int radiusIndex = request.indexOf("radius=");
  if (radiusIndex != -1) {
    int startPos = radiusIndex + 7; // Length of "radius="
    int endPos = request.indexOf('&', startPos);
    if (endPos == -1) endPos = request.indexOf(' ', startPos);
    if (endPos == -1) endPos = request.length();
    
    String radiusStr = request.substring(startPos, endPos);
    float radius = radiusStr.toFloat();
    
    // Constrain radius to reasonable limits
    if (radius > 0 && radius <= 1000) {
      return radius;
    }
  }
  return defaultRadius;
}

// Extract turning depth parameter from URL
float extractDepthParameter(String request, float defaultDepth) {
  int depthIndex = request.indexOf("depth=");
  if (depthIndex != -1) {
    int startPos = depthIndex + 6; // Length of "radius="
    int endPos = request.indexOf('&', startPos);
    if (endPos == -1) endPos = request.indexOf(' ', startPos);
    if (endPos == -1) endPos = request.length();
    
    String depthStr = request.substring(startPos, endPos);
    float depth = depthStr.toFloat();
    
    // Constrain radius to reasonable limits
    if (depth > 0 && depth <= 5) {
      return depth;
    }
  }
  return defaultDepth;
}

// Handle incoming WiFi commands (non-blocking)
void handleWiFiCommands() {
  WiFiClient client = server.available();
  
  if (client) {
    String request = "";
    unsigned long timeout = millis();

    while (client.connected() && millis() - timeout < 2000) {
      if (client.available()) {
        char c = client.read();
        request += c;

        if (request.endsWith("\r\n\r\n")) {
          break; // full HTTP header received
        }
      }
    }

    // DEBUG
    // Serial.println("=== Request ===");
    // Serial.println(request);
    // Serial.println("===============");

    if (request.length() > 0) {
      String response = processWiFiCommand(request);
      if (response.startsWith("{\"lat\":")) {
        sendWiFiResponse(client, response, "application/json");
      }
      else {
        sendWiFiResponse(client, response);
      }
    }

    // client.stop();
  }
}

// Send HTTP response
void sendWiFiResponse(WiFiClient client, String message, String contentType = "text/html") {
  client.print("HTTP/1.1 200 OK\r\n");
  client.print("Content-Type: " + contentType + "\r\n");
  client.print("Access-Control-Allow-Origin: *\r\n");
  client.print("Connection: close\r\n");
  client.print("Content-Length: ");
  client.print(message.length());
  client.print("\r\n\r\n");
  client.print(message);

  client.flush();
  delay(10);  
  client.stop();
}
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
